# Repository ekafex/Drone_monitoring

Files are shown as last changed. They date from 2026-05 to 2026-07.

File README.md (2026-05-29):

# Drone Atmospheric Monitoring Project 

This is an **R&D project funded by a AADF/READ grant** to build a **mobile atmospheric monitoring system** using a drone platform. The system architecture consists of **three measurement nodes**:

* **1 drone-mounted monitoring station**
* **1 fixed ground reference station**
* **1 mobile ground monitoring station** 

The drone platform is a **DJI Matrice 350 RTK**.

## Project Goal

Develop a **low-cost environmental monitoring system** capable of:

* mapping **air-pollution hotspots**
* performing **vertical atmospheric profiles**
* comparing drone measurements with **ground reference stations**

The system focuses on **relative air-quality indices rather than regulatory-grade concentrations**, to reduce integration complexity and cost.

## Sensor Strategy

Instead of multiple individual sensors (PM + gas + environmental), the system uses a **single integrated environmental node**:

**Primary sensor**

* **Sensirion SEN55**

    * PM1 / PM2.5 / PM4 / PM10
    * Temperature
    * Humidity
    * VOC index
    * NOx index
    * I²C interface

Advantages:

* factory calibrated
* digital output
* minimal analog electronics
* easier integration and maintenance

Optional upgrades discussed:

* **SCD4x CO₂ sensor**
* **SPS30 PM sensor for cross-validation**

## Electronics Architecture

Each station uses the same electronics design.

Core components:

**Microcontroller**

* ESP32-S3-DevKitC-1U development board

**Positioning**

* u-blox NEO-M9N GNSS module

**Communication**

* LoRa (868 MHz) telemetry

**Data storage**

* microSD logging

**Power**

* LiPo battery (drone/mobile)
* DC-DC regulators

## Communication Architecture

Telemetry uses **point-to-point LoRa (868 MHz)**.

Structure:

Drone node
→ LoRa
→ Ground station receiver

A LoRaWAN gateway is optional for later expansion.

## Airflow and Sensor Placement

Drone airflow strongly affects measurements.

Recommended design:

* **Side boom mounting**
* sensor inlet placed **~0.7–1.0 m from drone center**
* **aspirated sampling inlet** using a small fan
* **short inlet tubing**

This minimizes rotor downwash interference.

## Calibration Strategy

Because the system uses **relative air-quality indices**, calibration relies on **co-location** instead of expensive gas calibrators.

Procedure:

1. Run all stations **side-by-side for 1–2 weeks**
2. Compare sensor outputs
3. derive correction factors
4. validate against any available **reference station**

Industrial calibration devices exist but are **too expensive** for this project.

## Flight Sampling Protocol

Recommended drone measurement strategy:

1. Fly to location
2. **hover sampling segments (10–30 s)**
3. move to next point
4. repeat

Avoid measuring during rapid motion.

Use:

* vertical profiles
* grid sampling
* repeated transects

## System Deployment

Final system will include:

**Drone station**

* SEN55
* ESP32
* GNSS
* LoRa
* microSD
* aspirated inlet

**Fixed ground station**

* same sensors
* weatherproof enclosure
* continuous operation

**Mobile ground station**

* same hardware
* portable enclosure

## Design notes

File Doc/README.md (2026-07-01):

# PCB wiring



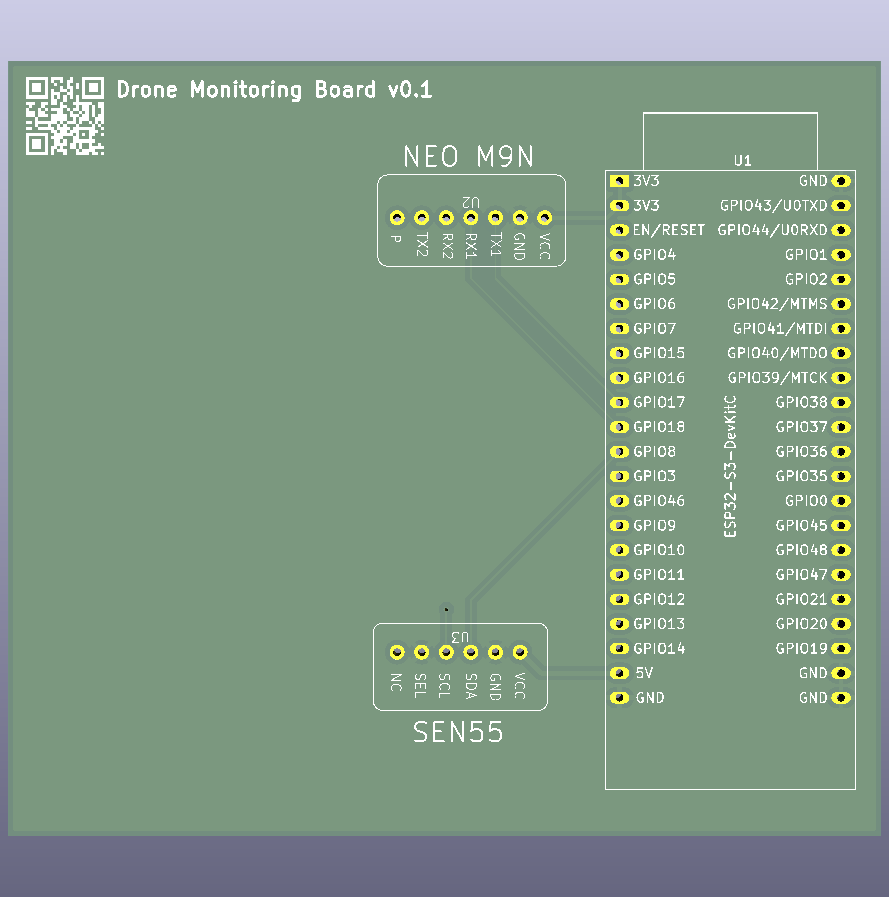
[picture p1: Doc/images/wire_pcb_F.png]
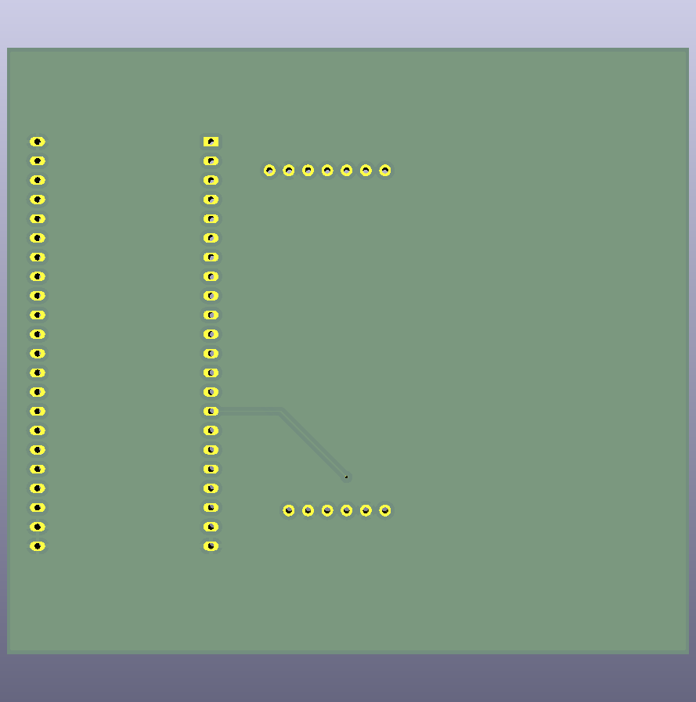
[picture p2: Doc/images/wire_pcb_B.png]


## ESP32-S3-DevKitC-1u

User guide for [ESP32-S3-DevKitC-1](https://docs.espressif.com/projects/esp-dev-kits/en/latest/esp32s3/esp32-s3-devkitc-1/user_guide_v1.1.html)

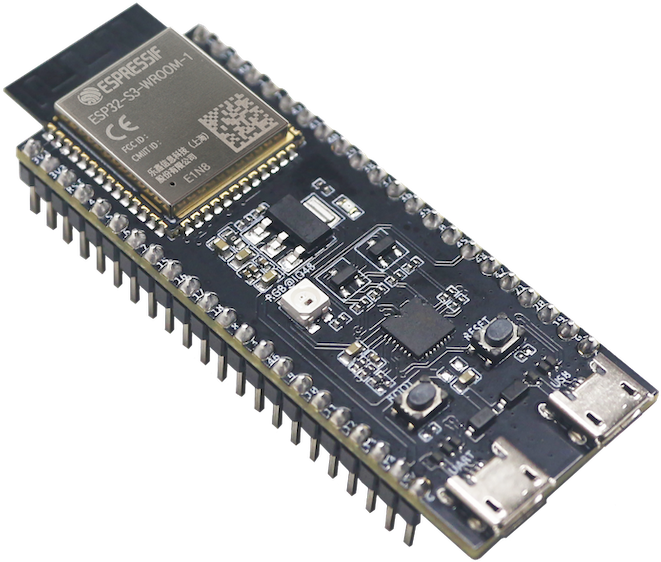
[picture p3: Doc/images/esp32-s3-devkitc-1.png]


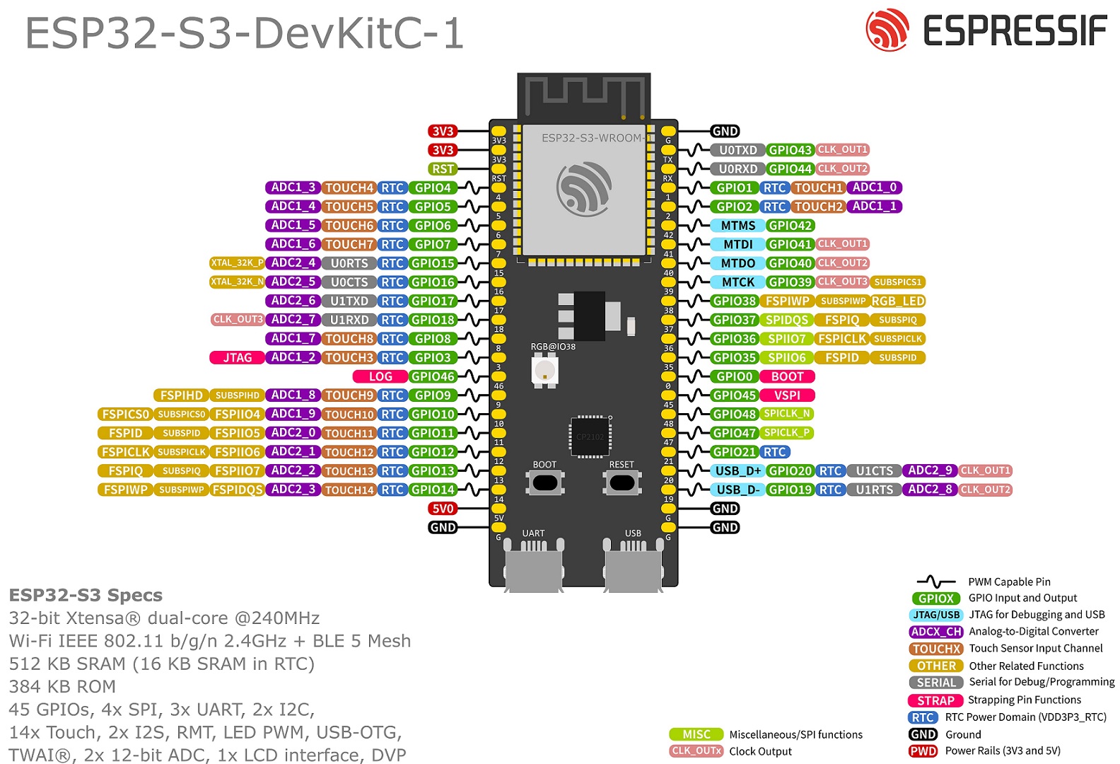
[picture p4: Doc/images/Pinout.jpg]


## Sensirion SEN55

[SEN55 Datasheet](https://sensirion.com/products/catalog/SEN55)

This is the Sensirion SEN5X library for Arduino using the
modules I2C interface.

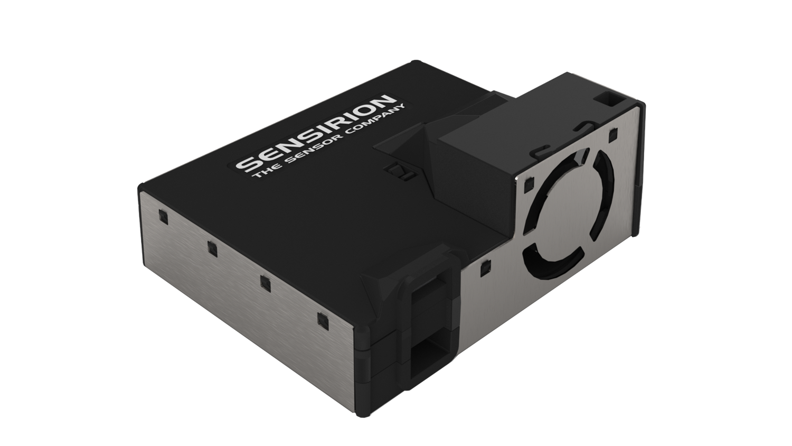
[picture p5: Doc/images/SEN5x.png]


| *SEN5X* |  *Arduino*  | *Jumper Wire* | ESP32 pin |
| :-----: | :---: | :---: | :---: |
| VCC | 5V | Red | 5V |
| GND | GND | Black | GND |
| SDA | SDA | Green | GPIO8 |
| SCL | SCL | Yellow | GPIO9 |
| SEL | GND for I2C | Blue | GND |

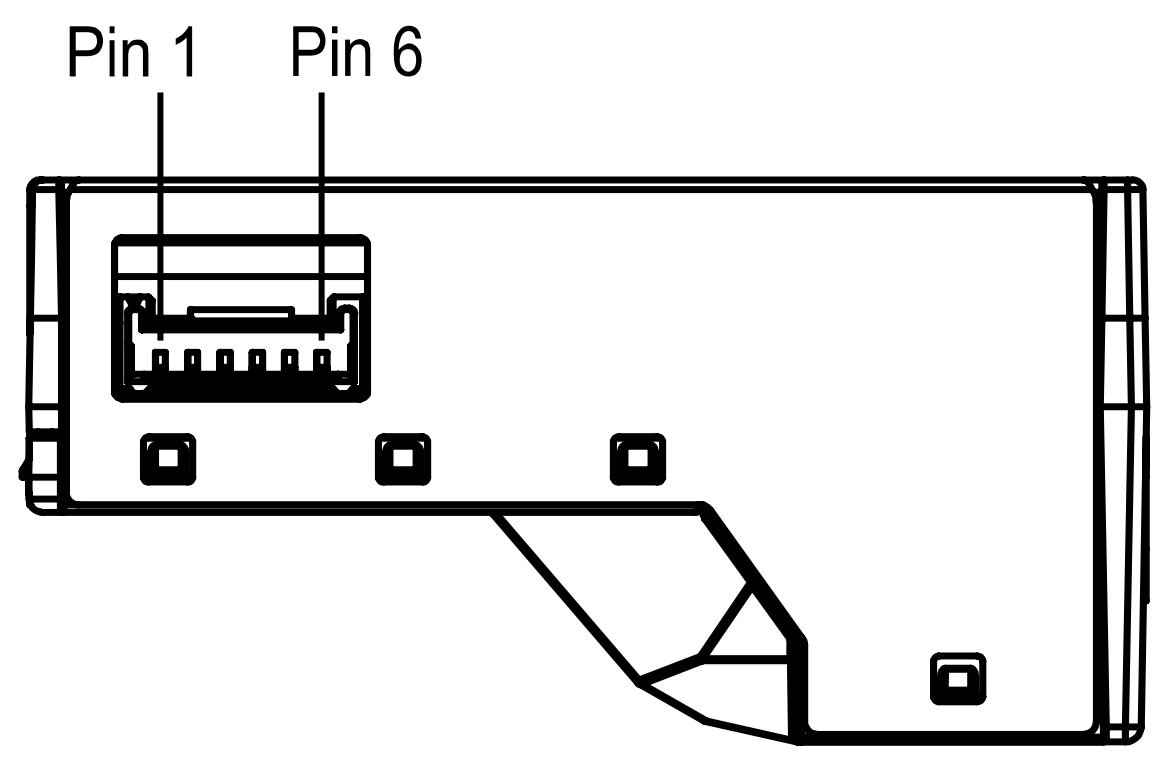
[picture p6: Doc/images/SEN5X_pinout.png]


| *Pin* | *Name* | *Description* | *Comments* |
| ----- | --- | --- | --- |
| 1 | VCC | Supply Voltage | 5V ±10% |
| 2 | GND | Ground |
| 3 | SDA | I2C: Serial data input / output | TTL 5V and LVTTL 3.3V compatible |
| 4 | SCL | I2C: Serial clock input | TTL 5V and LVTTL 3.3V compatible |
| 5 | SEL | Interface select | Pull to GND to select I2C |
| 6 | NC | Do not connect |

## UBLOX NEO M9N-00B

[Ublox NEO M9N-00B](https://www.u-blox.com/en/product/neo-m9n-module?legacy=Current#Documentation-&-resources)

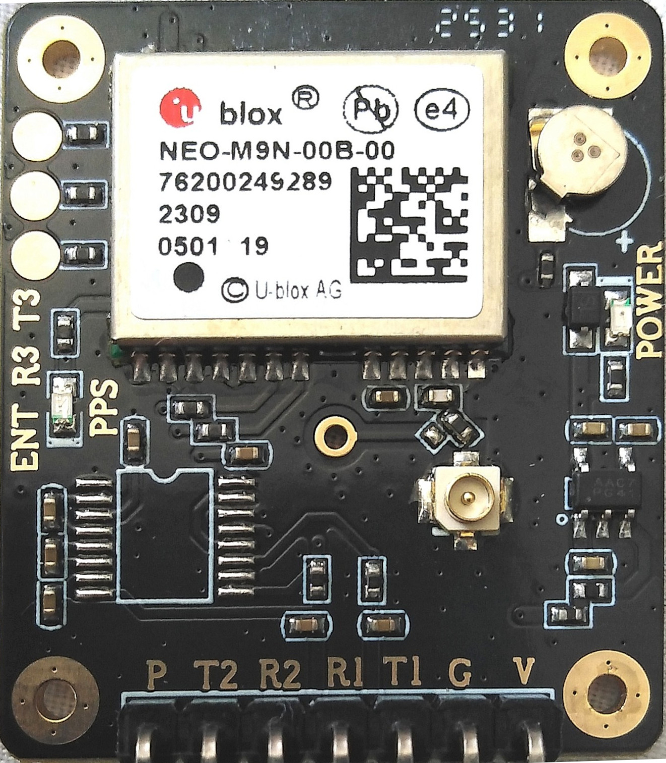
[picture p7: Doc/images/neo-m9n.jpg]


## LoRa LAMBDA62-8S (868MHz)

[LAMBDA62 Datasheet](https://www.rfsolutions.co.uk/radio-modules/lambda-62-lora-transceiver-module-20km-featuring-semtech-sx1262/)

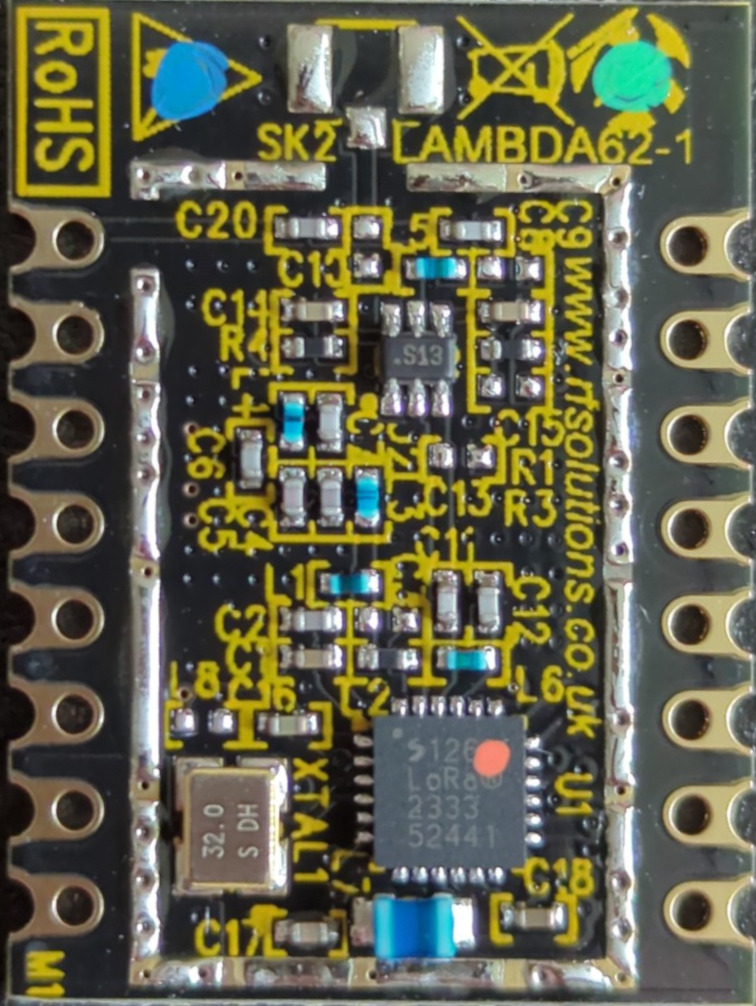
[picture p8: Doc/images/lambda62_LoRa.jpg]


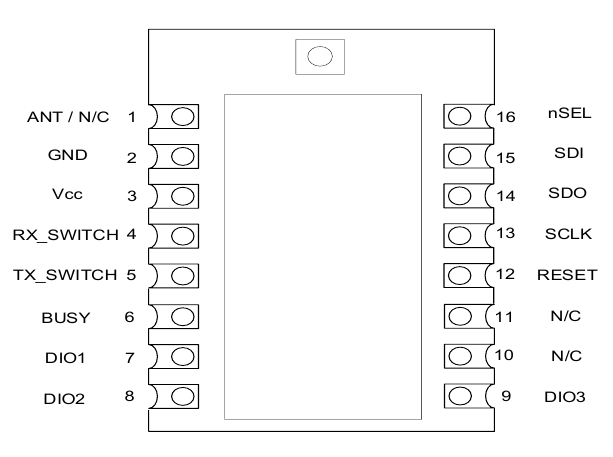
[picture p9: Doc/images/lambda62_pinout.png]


## Adafruit MicroSD BFF

[Reference](https://www.adafruit.com/product/5683)

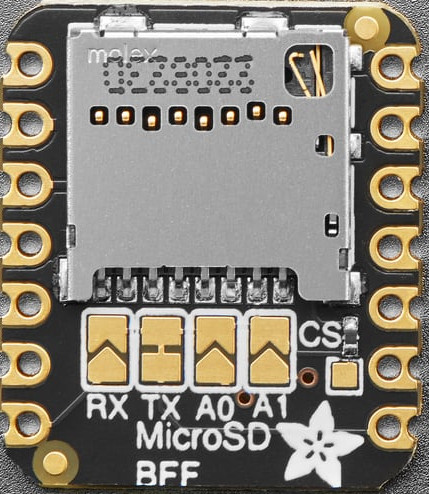
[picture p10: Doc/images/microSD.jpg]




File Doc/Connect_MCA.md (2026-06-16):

## RTEC digiBASE-RH Python acquisition setup

### 1. Linux / Debian / Raspberry Pi OS

Install system USB support and Python tools:

```bash
sudo apt update
sudo apt install python3 python3-venv python3-pip libusb-1.0-0
```

Create an environment:

```bash
python3 -m venv ~/venvs/digibase
source ~/venvs/digibase/bin/activate
pip install --upgrade pip
pip install digibase numpy matplotlib pyusb
```

Create the firmware directory:

```bash
mkdir -p ~/.digiBase
```

Copy ORTEC firmware files there:

```bash
cp digiBase.rbf ~/.digiBase/
cp digiBaseRH.rbf ~/.digiBase/
```

Set USB permissions:

```bash
sudo nano /etc/udev/rules.d/99-ortec-digibase.rules
```

Add:

```text
SUBSYSTEM=="usb", ATTR{idVendor}=="0a2d", ATTR{idProduct}=="001f", MODE="0666", GROUP="plugdev"
```

Reload:

```bash
sudo udevadm control --reload-rules
sudo udevadm trigger
sudo usermod -aG plugdev $USER
```

Then unplug/replug the digiBASE and log out/in.

Check:

```bash
lsusb
```

Expected:

```text
0a2d:001f ORTEC digiBASE-RH
```

### 2. Windows

There are two routes.

For **official ORTEC software**, install ORTEC CONNECTIONS/MAESTRO and use the vendor driver. The digiBASE manual describes installation through CONNECTIONS Driver Update Kit, MAESTRO, and MCB Configuration. ([ManualsLib](https://www.manualslib.com/manual/1990334/Ametek-Ortec-Digibase.html?utm_source=chatgpt.com))

For **Python/libusb access**, install:

```powershell
python -m pip install digibase numpy matplotlib pyusb
```

Then copy:

```text
digiBase.rbf
digiBaseRH.rbf
```

to a convenient folder, for example:

```text
C:\Users\<your-user>\.digiBase\
```

If Python cannot open the USB device, Windows likely needs a generic USB driver such as **WinUSB** or **libusbK** installed for the digiBASE interface. Zadig is commonly used for this purpose; it installs generic USB drivers such as WinUSB/libusbK for libusb-based applications. ([AlternativeTo](https://alternativeto.net/software/zadig/about/?utm_source=chatgpt.com))

Important: replacing the ORTEC driver with WinUSB/libusbK may stop MAESTRO from seeing the device until you revert the driver.

## Minimal spectrum acquisition script

Save as `digibase_take_spectrum.py`:

```python
#!/usr/bin/env python3

import argparse
import time
from pathlib import Path

import numpy as np
import matplotlib.pyplot as plt

from digibase import digiBase

def main():
    parser = argparse.ArgumentParser(
        description="Acquire one PHA spectrum from an ORTEC digiBASE/digiBASE-RH."
    )

    parser.add_argument("--hv", type=float, default=600.0,
                        help="PMT high voltage in volts. Start conservatively.")
    parser.add_argument("--time", type=float, default=10.0,
                        help="Acquisition time in seconds.")
    parser.add_argument("--fine-gain", type=float, default=1.0,
                        help="ADC fine gain.")
    parser.add_argument("--lld", type=int, default=24,
                        help="Lower-level discriminator in ADC channels.")
    parser.add_argument("--out", type=str, default="spectrum",
                        help="Output basename without extension.")

    args = parser.parse_args()

    outbase = Path(args.out)

    print("Connecting to digiBASE...")
    base = digiBase()

    print(f"Serial number: {base.serial}")

    print(f"Setting HV = {args.hv} V")
    base.hv = args.hv
    base.hv_enabled = True

    print(f"Setting fine gain = {args.fine_gain}")
    base.fine_gain = args.fine_gain

    print(f"Setting LLD = {args.lld}")
    base.lld = args.lld

    print("Setting PHA mode")
    base.set_acq_mode_pha()

    print("Clearing previous spectrum if supported...")
    try:
        base.clear()
    except Exception:
        pass

    print("Starting acquisition...")
    base.start()

    time.sleep(args.time)

    print("Stopping acquisition...")
    base.stop()

    spectrum = np.asarray(base.spectrum, dtype=np.int64)
    channels = np.arange(len(spectrum))

    txt_file = outbase.with_suffix(".txt")
    csv_file = outbase.with_suffix(".csv")
    png_file = outbase.with_suffix(".png")

    np.savetxt(txt_file, spectrum, fmt="%d")

    data = np.column_stack([channels, spectrum])
    np.savetxt(
        csv_file,
        data,
        delimiter=",",
        header="channel,counts",
        comments="",
        fmt=["%d", "%d"],
    )

    plt.figure()
    plt.plot(channels, spectrum)
    plt.xlabel("Channel")
    plt.ylabel("Counts")
    plt.title(f"digiBASE spectrum, {args.time:g} s, HV={args.hv:g} V")
    plt.grid(True)
    plt.tight_layout()
    plt.savefig(png_file, dpi=150)
    plt.show()

    print()
    print("Acquisition complete.")
    print(f"Channels:     {len(spectrum)}")
    print(f"Total counts: {spectrum.sum()}")
    print(f"Peak channel: {spectrum.argmax()}")
    print(f"Saved:        {txt_file}")
    print(f"Saved:        {csv_file}")
    print(f"Saved:        {png_file}")

if __name__ == "__main__":
    main()
```

Run:

```bash
python digibase_take_spectrum.py --hv 600 --time 30 --fine-gain 1.0 --lld 24 --out test_30s
```

This produces:

```text
test_30s.txt
test_30s.csv
test_30s.png
```

Start with a safe low HV, then increase only according to your PMT/scintillator specifications.

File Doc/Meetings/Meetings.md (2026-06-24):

# Group Meetings Detyrat

| Data Mbledhjes | Data Raportimit | Silvana | Gerti | Klaudio | Ervini |
| :---: | :---: | :--- | :--- | :--- | :--- |
| 16.06.2026 | **23.06.2026**  | Raport mbi instalimin dhe perdorimin e software-it te Evaluation Kit SEK-SEN55 | Raport mbi instalimin dhe data acquisition ne kompjuter nga gamma detector. Funksioni i librarise digibase ne python | Validimi i funksionit te te gjitha pajisjeve te blera per "Laboratorin e Aerodinamikes" | Raport mbi ecurine a firmware dhe lidhjes se te gjitha komponenteve baze te paketes se dronit (SEN55, GNSS, SD card & LoRa) |
| 23.06.2026 | **03.07.2026**  | Blerje online. Ri-evaluimi i buxhetit qe mund te alokohet per blerjet e reja. Raportim e ecurise | Venia ne pune e pajisjeve laboraorike. Raportim i ecurise | Investigimi i zhurmes e kanaleve te MCA te uleta. Rregullimi i delay ne matjet, dhe te kuptuarit e "list-mode". Raportim i ecurise. | Ndertimi i PCB per nensitemin e dronit me KiCAD. Raportimi i ecurise |
| | | | | | |

---

## Group Meeting Raportimet

| Data | Silvana | Gerti | Klaudio | Ervini |
| :---: | :--- | :--- | :--- | :--- |
| **23.06.2026** | 1. Software Sensiron u instalua por nuk punon pa u lidhur me sensorin (**status: pending**). 2. Nevoja per evaluation kit bridge per te lidhur sensorin me kompjuterin. | 1. Libraria funksionon, mund te lidhet ne menyre te sukseshme dhe te marri te dhena nga detektori gamma (**status: functional**). 2. Zhurme e pa identifikuar ne kanalet e uleta te MCA (**status: in progress**). 3. Perpjekje to mitigate duke bere nje delay midis powering dhe fillimit te matjeve (**status: in progress**). | 1. Te gjitha pajisjet e blera per laboratorin e aerodinamikes funksionojne. 2. Gypi pitot ka nevoje per nje mikrokontrollor per te lidhur me kompjuterin (Arduino nga lab i elektronikes). | 1. Shkrimi i draftit te pare te Firmware per paketen e dronit (**status: functional**). 2. Ndertimi i versionit v.0.1 e PCB manualisht (**status: functional**). 3. Ndertimi i wiring, BOM, dhe PCB profesionale ne KiCAD (**status: in progress**). |
| | | | | |

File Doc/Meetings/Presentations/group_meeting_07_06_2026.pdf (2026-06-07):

## Sistemi i Monitorimit Atmosferik me Dron

### Arkitektura e përditësuar, nënsistemet, varësitë dhe plani R&D

Draft për mbledhjen e grupit

Ervin K. – FSHN @ UT – Projekt R&D

June 7, 2026

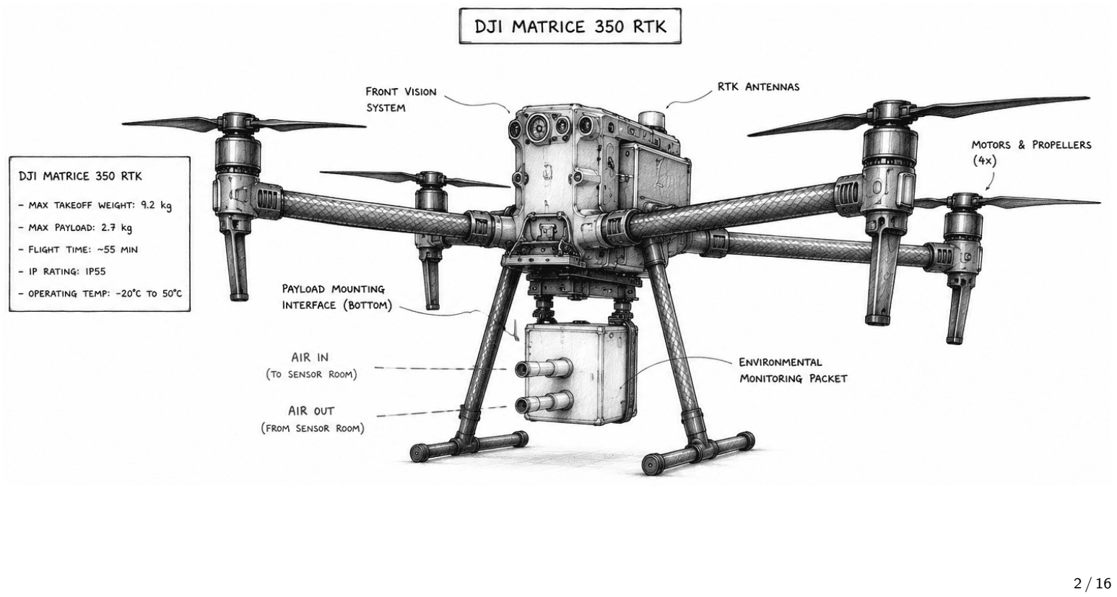
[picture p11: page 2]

### Qëllimi i kësaj mbledhjeje

Qëllimi kryesor
Të sinkronizojmë ekipin rreth arkitekturës aktuale të sistemit, përgjegjësive për nënsistemet, varësive dhe daljeve afatshkurtra.

### Duhet të qartësojmë - çfarë funksionon tashmë

### - çfarë mungon ende

### - çfarë e bllokon integrimin

### Dalja e mbledhjes - përgjegjësi të përditësuara për detyrat - afate realiste për nënsistemet

### - plan veprimi për 4–8 javët e ardhshme

### Arkitektura e përgjithshme e projektit

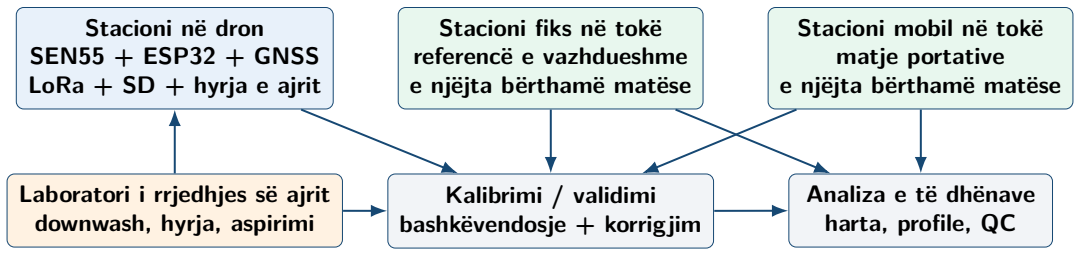
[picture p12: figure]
Stacioni në dron SEN55 + ESP32 + GNSS LoRa + SD + hyrja e ajrit; Stacioni fiks në tokë referencë e vazhdueshme e njëjta bërthamë matëse; Stacioni mobil në tokë matje portative e njëjta bërthamë matëse; Laboratori i rrjedhjes së ajrit downwash, hyrja, aspirimi; Kalibrimi / validimi bashkëvendosje + korrigjim; Analiza e të dhënave harta, profile, QC

### Afati i projektit: nga prototipi te matjet në terren

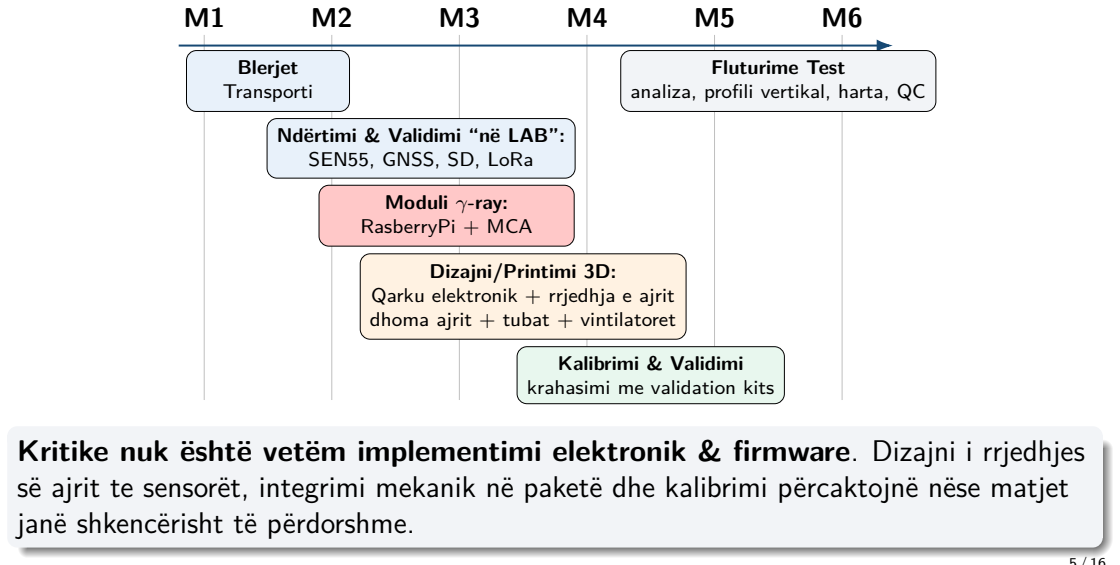
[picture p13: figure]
Blerjet Transporti; Ndërtimi & Validimi; “në LAB”:; SEN55, GNSS, SD, LoRa; Moduli γ-ray:; RasberryPi; + MCA; Dizajni/Printimi 3D: Qarku elektronik + rrjedhja e ajrit dhoma ajrit + tubat + vintilatoret; Kalibrimi & Validimi krahasimi me validation kits; Fluturime Test analiza, profili vertikal, harta, QC; janë shkencërisht të përdorshme.

Kritike nuk është vetëm implementimi elektronik & firmware. Dizajni i rrjedhjes së ajrit te sensorët, integrimi mekanik në paketë dhe kalibrimi përcaktojnë nëse matjet

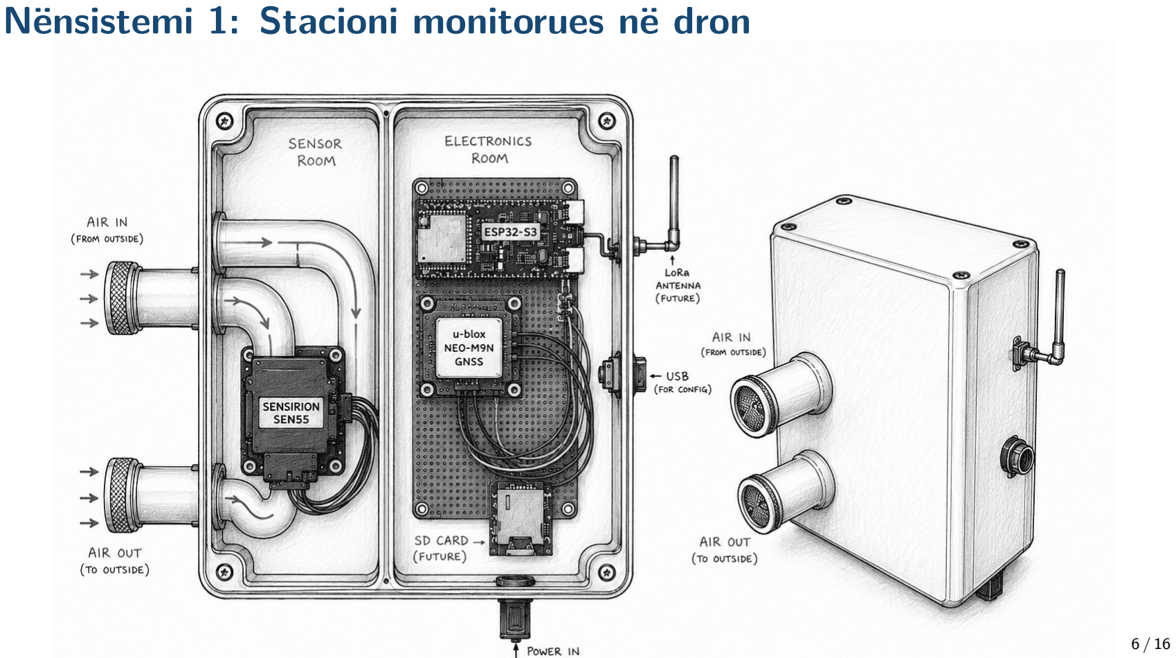
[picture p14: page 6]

### Nënsistemi 1: Stacioni monitorues në dron

### Nënsistemi 1: Stacioni monitorues në dron

Qëllimi
Të masë indikatorët atmosferikë përgjithësisht në profilin vertikal.
- Statusi: Vënia në punë e SEN55 dhe
GNSS ka filluar / është validuar
pjesërisht.
- Përgjegjësit: Ervini & Silvana
- Objektivi: Prototip në tavolinë & prototip i sigurt për dronin.
- Input: firmware, kapsula, krahët anësor (tubat), hyrje ajri, powerbank.
- Output: Një nyje në dron që prodhon te dnenat: data, ora, lat, long, alt, PM-t, VOC, NOx, Temp., RH
- Përdoret nga: kalibrimi, protokolli i fluturimit, analiza e të dhënave.
- Rreziqe/çështje të hapura: bias nga rrjedhja ajrit (droni/paketa), vibrimet, zhurmat, siguria në dron.

### Nënsistemi 2: Stacioni fiks në tokë

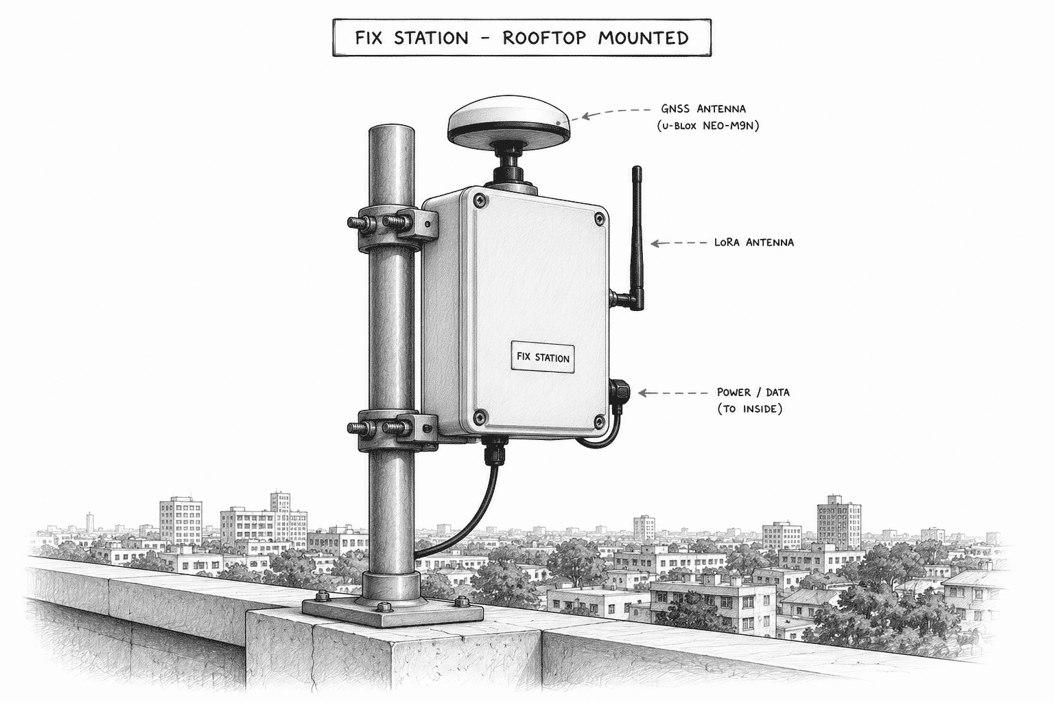
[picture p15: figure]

### Nënsistemi 2: Stacioni fiks në tokë

Qëllimi
Të ofrojë të dhëna lokale të vazhdueshme për krahasim, ndjekje të driftit dhe kalibrim me bashkëvendosje.
- Statusi: Arkitektura hardware është
përcaktuar; kapsulimi dhe rrjedhja e ajrit duhen ende validuar.
- Përgjegjësit: Silvana & Ervini
- Objektivi: Prototip për funksionim të vazhdueshëm jashtë.
- Input: SEN55, ESP32, GNSS/koha, ⃗v erës, SD, ventilator, kasë, energji.
- Output: Seri kohore stabël: data, ora, lat, long, alt, PM-t, VOC, NOx, Temp., RH, ⃗v e erës
- Përdoret nga: kalibrimi, validimi, matjet bazë.
- Rreziqe/çështje të hapura: mbrojtja nga moti, dizajni i hyrjes së ajrit, energjia afatgjatë, bias termik.

### Nënsistemi 3: Stacioni mobil në tokë

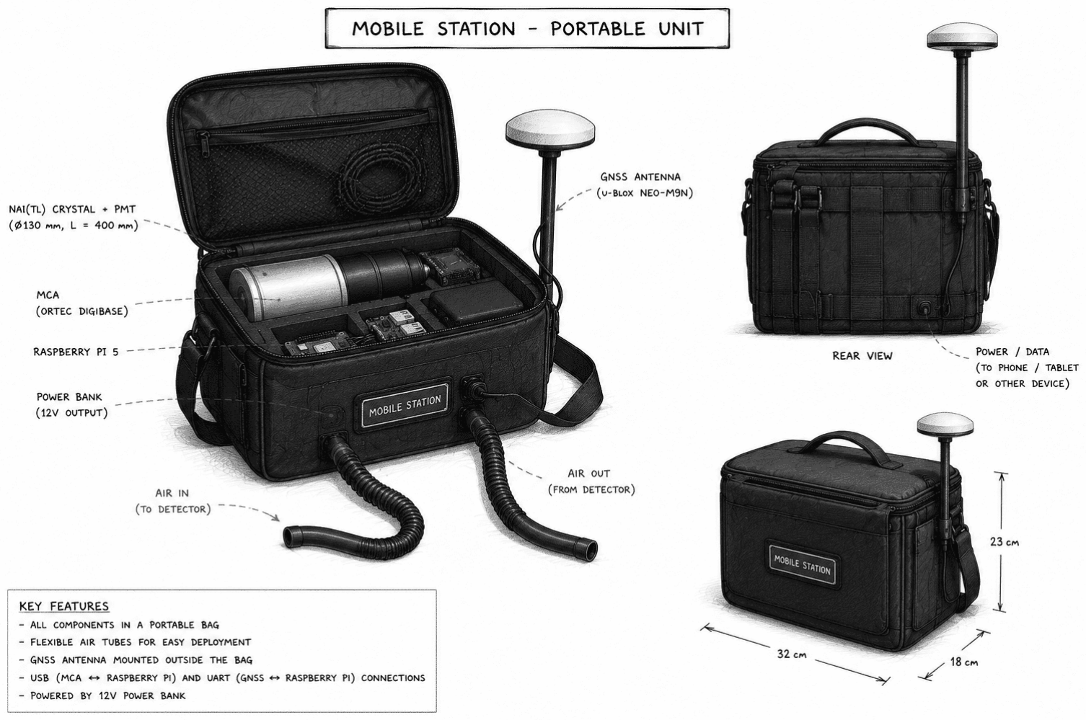
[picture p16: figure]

### Nënsistemi 3: Stacioni mobil në tokë

Qëllimi
Të mbështesë matje portative në tokë dhe të japë të dhëna krahasuese pranë vendndodhjeve të matjeve me dron.
- Statusi: E njëjta bërthamë elektronike
si stacioni fiks; kasa portative është në pritje.
- Përgjegjësit: Klaudio & Gerti
- Objektivi: Nyjë portative me bateri.
- Output: Matje të gjeolokalizuara në ecje / të mbajtura / mobile.
- Input: firmuer i përbashkët, bateri, kasë, dorezë/montim, SD.
- Përdoret nga: matje të hotspoteve, krahasim dron-tokë, validim hartash.
- Rreziqe/çështje të hapura: artefakte nga lëvizja, ekspozim ndaj temperaturës, lartësi jo e njëtrajtshme e mostrimit.

### Nënsistemi 4: Stacioni γ-ray

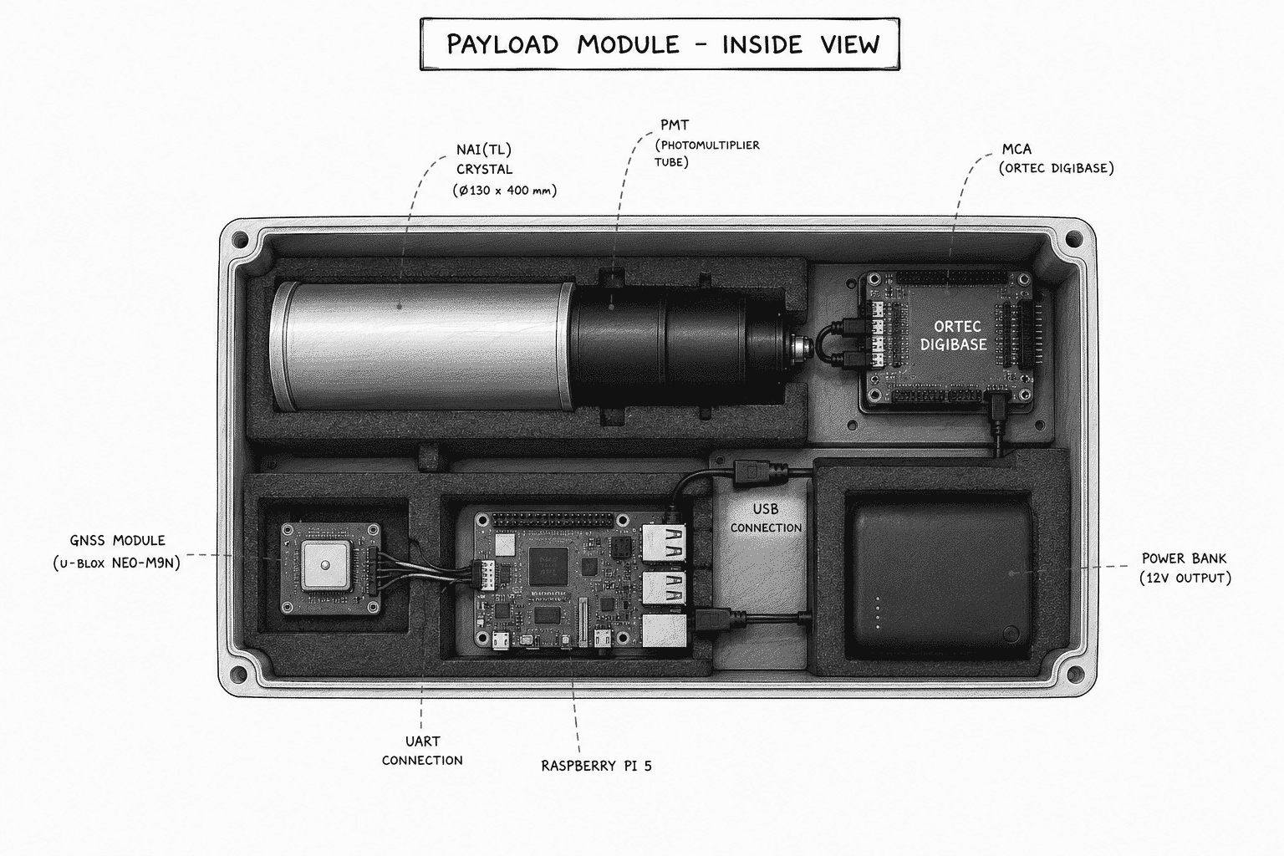
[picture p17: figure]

### Nënsistemi 4: Stacioni γ-ray

Qëllimi
Te ndërtojë harta të hotspoteve radioaktive me dron.
- Statusi: Detectori NaI + PMT + MCA
& Rasberry Pi + GNSS + LoRa + SD.
- Përgjegjësit: Gerti & Ervini
- Objektivi: Nyjë portative me bateri (powerbank).
- Input: Simulimet Geant4, firmware, bateri, kasë montim dron.
- Output: Heatmap: channel counts vs. time.
- Përdoret nga: hotspot maps, validim hartash radioaktiviteti.
- Rreziqe/çështje të hapura: Pesha detektorit, koha e ekspozimit/koha baterise se dronit.

### Nënsistemi 5: Laboratori i rrjedhjes së ajrit

Qëllimi
Të studiojmë nivelin e turbullimit të ajrit nga helikat e dronit, optimizimin e rrjedhjes së ajrit në dhomën e sensorëve dhe optimizimin e aerodinamikës së paketave në dron.
- Statusi: Kanë ardhur pajisjet ???
- Përgjegjësit: Klaudio & Gerti
- Objektivi: Të ngrihet lab për të studiuar turbullirat e dronit.
- Input: Simulimet aerodinamike.
- Output: Hartën 3D të shpejtësisë së ajrit rrotull dronit.
- Përdoret nga: Dizajni mekanik.
- Rreziqe/çështje të hapura: Mungesa e gjithë pajisjeve laboratorike për të bërë matjet. Mungesë eksperience në simulimet aerodinamike

### Grupet që duhen ngritur

Grupet
- Shkrim Firmware
- Dizajn Qarku/PCB
- Telemetria LoRa
- Dizajni CAD dhe Printimi 3D i pjesëve mekanike
- Kalibrimi dhe Validimi përdorimi i “Validation Kits”
- Pipeline & Databaza
- Sofware: Analizë & Vizualizimin e të dhënave

Vendime për t’u marrë sot:
1. Përgjegjësat për secilin nënsistem?
2. Funksionaliteti minmal i pajisjes për të filluar testet e para me dron?
3. Strategjia për dizajnin e kasave të stacionit fiks dhe atij mobil?
4. Cilat teste të rrjedhjes së ajrit janë të detyrueshme para montimit në dron?
5. Cili format log-u duhet bërë standard i projektit?
6. Cila është data e matjeve te para?

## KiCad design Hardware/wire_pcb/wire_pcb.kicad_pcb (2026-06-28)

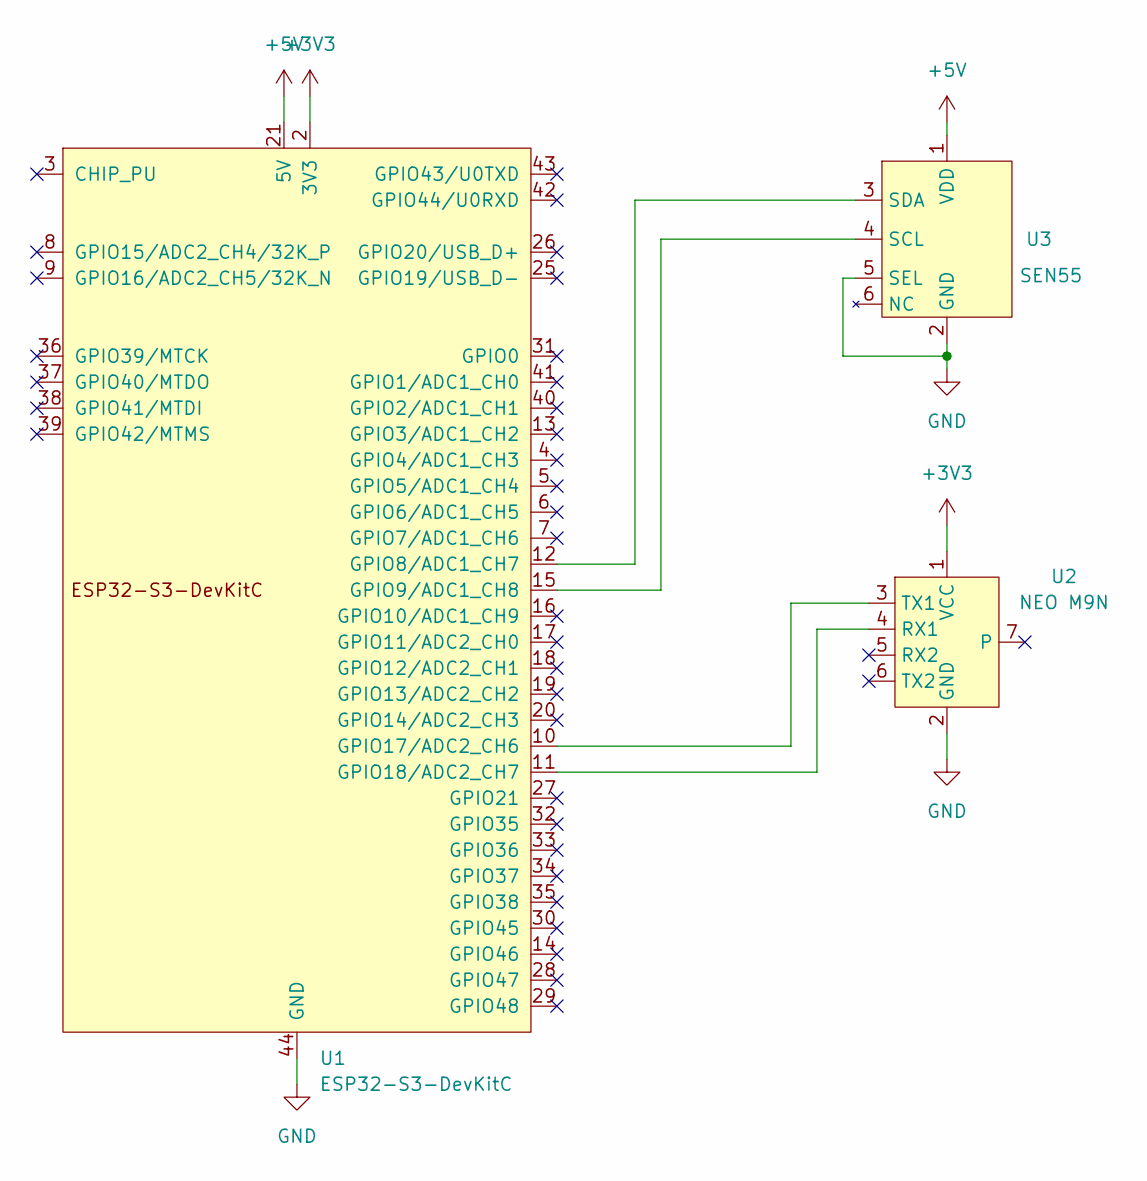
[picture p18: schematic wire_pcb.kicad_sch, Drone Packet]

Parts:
U1: ESP32-S3-DevKitC
U2: NEO M9N
U3: SEN55

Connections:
+3V3: U1.1 (3V3), U1.2 (3V3), U2.1 (VCC)
+5V: U1.21 (5V), U3.1 (VDD)
GND: U1.22 (GND), U1.23 (GND), U1.24 (GND), U1.44 (GND), U2.2 (GND), U3.2 (GND), U3.5 (SEL)
unnamed: U1.12 (GPIO8/ADC1_CH7), U3.3 (SDA)
unnamed: U1.15 (GPIO9/ADC1_CH8), U3.4 (SCL)
unnamed: U1.10 (GPIO17/ADC2_CH6), U2.3 (TX1)
unnamed: U1.11 (GPIO18/ADC2_CH7), U2.4 (RX1)

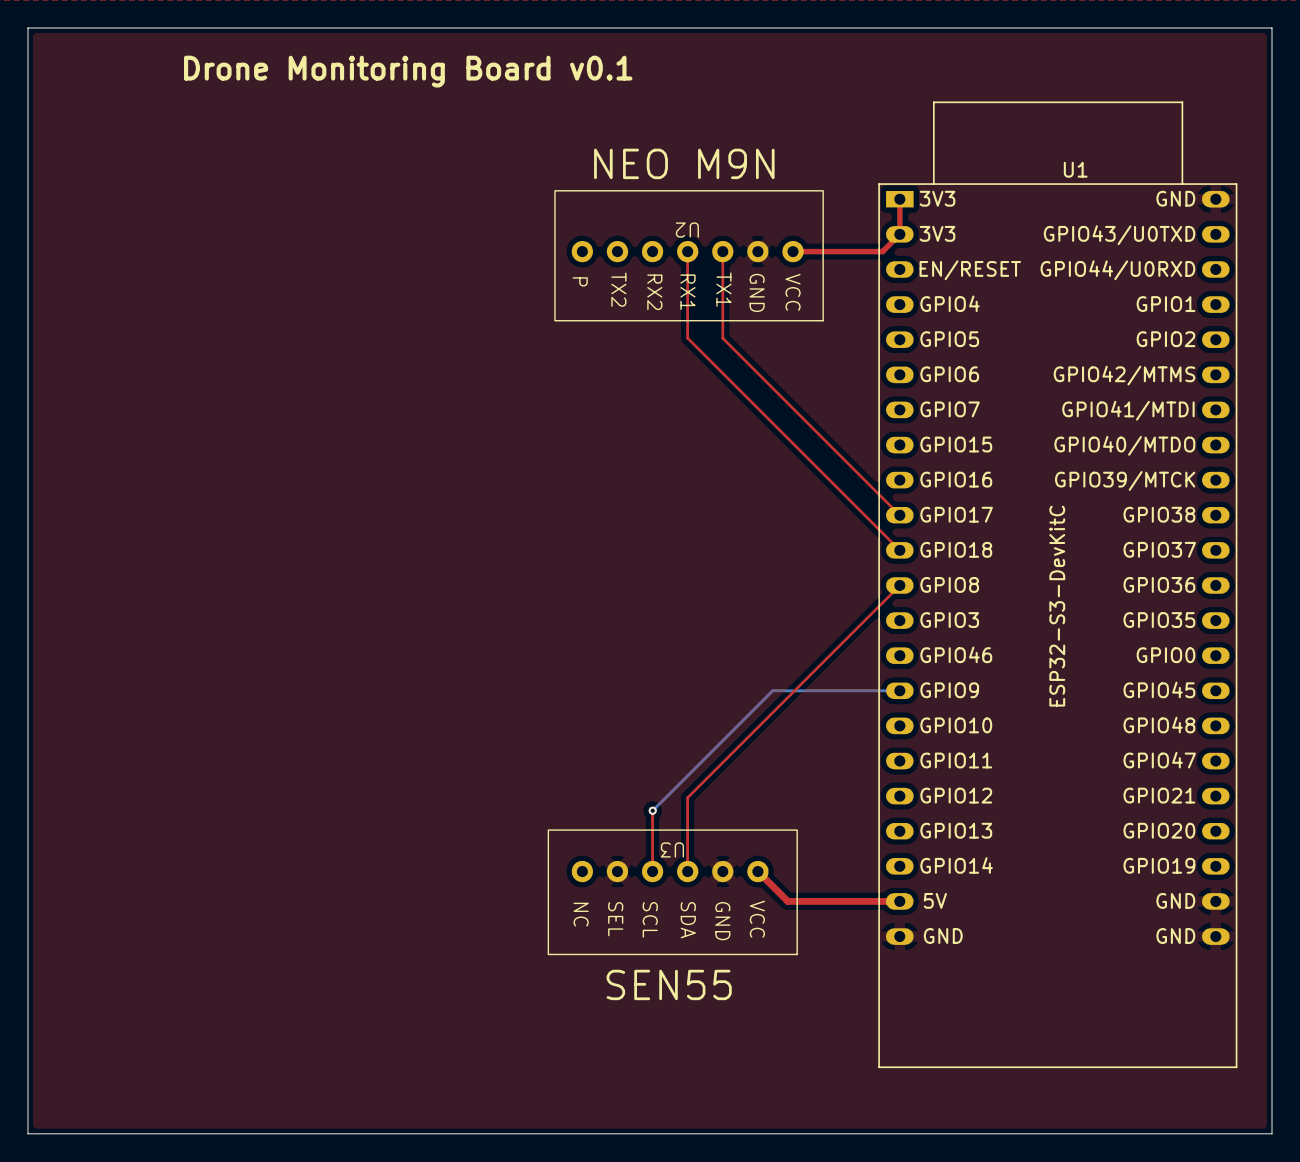
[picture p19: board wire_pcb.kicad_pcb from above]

Board: 2 copper layers, 90.0 x 80.0 mm, 3 parts (0 on the bottom side), 7 nets.

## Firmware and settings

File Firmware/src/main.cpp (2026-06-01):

#include <Arduino.h>
#include <Wire.h>
#include <math.h>

#include <SensirionI2CSen5x.h>
#include <SparkFun_u-blox_GNSS_v3.h>

// -----------------------------------------------------------------------------
// Pin configuration
// -----------------------------------------------------------------------------

constexpr uint8_t I2C_SDA_PIN = 8;
constexpr uint8_t I2C_SCL_PIN = 9;

constexpr uint8_t GNSS_RX_PIN = 18;  // ESP32 RX  <- GNSS T1 / TX
constexpr uint8_t GNSS_TX_PIN = 17;  // ESP32 TX  -> GNSS R1 / RX

constexpr uint32_t SERIAL_BAUD = 115200;
constexpr uint32_t GNSS_BAUD_PRIMARY = 38400;
constexpr uint32_t GNSS_BAUD_FALLBACK = 9600;

// SEN55 should normally be read at ~1 Hz.
constexpr uint32_t SEN55_READ_PERIOD_MS = 1000;

// GNSS PVT can be polled faster; it will only update when new data are ready.
constexpr uint32_t GNSS_POLL_PERIOD_MS = 200;

// For now this is the period of the combined printed/logged record.
// Later this can become the SD-card / LoRa publication period.
constexpr uint32_t RECORD_PERIOD_MS = 1000;

// -----------------------------------------------------------------------------
// Global driver objects
// -----------------------------------------------------------------------------

SensirionI2CSen5x sen5x;
HardwareSerial GNSSSerial(1);
SFE_UBLOX_GNSS_SERIAL gnss;

// -----------------------------------------------------------------------------
// Data structures
// -----------------------------------------------------------------------------

struct Sen55Sample {
    bool valid = false;
    uint32_t timestamp_ms = 0;

    float pm1p0 = NAN;
    float pm2p5 = NAN;
    float pm4p0 = NAN;
    float pm10p0 = NAN;

    float humidity = NAN;
    float temperature = NAN;
    float vocIndex = NAN;
    float noxIndex = NAN;
};

struct GnssSample {
    bool valid = false;
    uint32_t timestamp_ms = 0;

    double latitude_deg = NAN;
    double longitude_deg = NAN;
    double altitude_msl_m = NAN;

    uint8_t satellites = 0;
    uint8_t fixType = 0;

    uint16_t year = 0;
    uint8_t month = 0;
    uint8_t day = 0;
    uint8_t hour = 0;
    uint8_t minute = 0;
    uint8_t second = 0;
};

struct MeasurementRecord {
    uint32_t timestamp_ms = 0;
    Sen55Sample sen55;
    GnssSample gnss;
};

Sen55Sample latestSen55;
GnssSample latestGnss;

// -----------------------------------------------------------------------------
// Small utility functions
// -----------------------------------------------------------------------------

void printSensirionError(const char* operation, uint16_t error)
{
    char errorMessage[256];
    errorToString(error, errorMessage, sizeof(errorMessage));

    Serial.print("[SEN55] ");
    Serial.print(operation);
    Serial.print(" failed: ");
    Serial.println(errorMessage);
}

void printFloatOrNA(float value, uint8_t digits)
{
    if (isnan(value)) {
        Serial.print("n/a");
    } else {
        Serial.print(value, digits);
    }
}

void printDoubleOrNA(double value, uint8_t digits)
{
    if (isnan(value)) {
        Serial.print("n/a");
    } else {
        Serial.print(value, digits);
    }
}

// -----------------------------------------------------------------------------
// SEN55 subsystem
// -----------------------------------------------------------------------------

bool initSen55()
{
    Wire.begin(I2C_SDA_PIN, I2C_SCL_PIN);
    sen5x.begin(Wire);

    uint16_t error = sen5x.deviceReset();
    if (error) {
        printSensirionError("deviceReset", error);
        return false;
    }

    delay(100);

    const float tempOffset = 0.0f;
    error = sen5x.setTemperatureOffsetSimple(tempOffset);
    if (error) {
        printSensirionError("setTemperatureOffsetSimple", error);
        // Not fatal for basic operation.
    } else {
        Serial.print("[SEN55] Temperature offset set to ");
        Serial.print(tempOffset);
        Serial.println(" deg C");
    }

    error = sen5x.startMeasurement();
    if (error) {
        printSensirionError("startMeasurement", error);
        return false;
    }

    Serial.println("[SEN55] Measurement started");
    return true;
}

bool readSen55(Sen55Sample& sample)
{
    sample.timestamp_ms = millis();

    uint16_t error = sen5x.readMeasuredValues(
        sample.pm1p0,
        sample.pm2p5,
        sample.pm4p0,
        sample.pm10p0,
        sample.humidity,
        sample.temperature,
        sample.vocIndex,
        sample.noxIndex
    );

    if (error) {
        sample.valid = false;
        printSensirionError("readMeasuredValues", error);
        return false;
    }

    sample.valid = true;
    return true;
}

// -----------------------------------------------------------------------------
// GNSS subsystem
// -----------------------------------------------------------------------------

bool tryBeginGnssAtBaud(uint32_t baud)
{
    GNSSSerial.end();
    delay(50);

    GNSSSerial.begin(baud, SERIAL_8N1, GNSS_RX_PIN, GNSS_TX_PIN);
    delay(200);

    Serial.print("[GNSS] Trying UART baud ");
    Serial.println(baud);

    return gnss.begin(GNSSSerial);
}

bool initGnss()
{
    if (!tryBeginGnssAtBaud(GNSS_BAUD_PRIMARY)) {
        if (!tryBeginGnssAtBaud(GNSS_BAUD_FALLBACK)) {
            Serial.println("[GNSS] Not detected");
            return false;
        }
    }

    Serial.println("[GNSS] Detected");

    // Use UBX binary output on UART1. This reduces unnecessary NMEA traffic.
    // If this call fails, basic reading can still work.
    if (!gnss.setUART1Output(COM_TYPE_UBX)) {
        Serial.println("[GNSS] Warning: could not set UART1 output to UBX only");
    }

    return true;
}

bool readGnss(GnssSample& sample)
{
    // getPVT returns true when a fresh PVT solution is available.
    if (!gnss.getPVT()) {
        return false;
    }

    sample.timestamp_ms = millis();

    sample.latitude_deg = gnss.getLatitude() / 10000000.0;
    sample.longitude_deg = gnss.getLongitude() / 10000000.0;
    sample.altitude_msl_m = gnss.getAltitudeMSL() / 1000.0;

    sample.satellites = gnss.getSIV();
    sample.fixType = gnss.getFixType();

    sample.year = gnss.getYear();
    sample.month = gnss.getMonth();
    sample.day = gnss.getDay();
    sample.hour = gnss.getHour();
    sample.minute = gnss.getMinute();
    sample.second = gnss.getSecond();

    // fixType: 0 = no fix, 2 = 2D, 3 = 3D, etc.
    sample.valid = (sample.fixType >= 2);

    return true;
}

// -----------------------------------------------------------------------------
// Output / logging layer
// Later replace this with SD-card append + LoRa packet generation.
// -----------------------------------------------------------------------------

MeasurementRecord makeRecord()
{
    MeasurementRecord record;
    record.timestamp_ms = millis();
    record.sen55 = latestSen55;
    record.gnss = latestGnss;
    return record;
}

void printRecordHumanReadable(const MeasurementRecord& record)
{
    Serial.println();
    Serial.print("[RECORD] t_ms=");
    Serial.println(record.timestamp_ms);

    Serial.print("  SEN55 valid=");
    Serial.print(record.sen55.valid ? "yes" : "no");
    Serial.print(" PM1=");
    printFloatOrNA(record.sen55.pm1p0, 2);
    Serial.print(" PM2.5=");
    printFloatOrNA(record.sen55.pm2p5, 2);
    Serial.print(" PM4=");
    printFloatOrNA(record.sen55.pm4p0, 2);
    Serial.print(" PM10=");
    printFloatOrNA(record.sen55.pm10p0, 2);
    Serial.print(" H=");
    printFloatOrNA(record.sen55.humidity, 2);
    Serial.print(" T=");
    printFloatOrNA(record.sen55.temperature, 2);
    Serial.print(" VOC=");
    printFloatOrNA(record.sen55.vocIndex, 0);
    Serial.print(" NOx=");
    printFloatOrNA(record.sen55.noxIndex, 0);
    Serial.println();

    Serial.print("  GNSS valid=");
    Serial.print(record.gnss.valid ? "yes" : "no");
    Serial.print(" fixType=");
    Serial.print(record.gnss.fixType);
    Serial.print(" SIV=");
    Serial.print(record.gnss.satellites);
    Serial.print(" lat=");
    printDoubleOrNA(record.gnss.latitude_deg, 7);
    Serial.print(" lon=");
    printDoubleOrNA(record.gnss.longitude_deg, 7);
    Serial.print(" alt_m=");
    printDoubleOrNA(record.gnss.altitude_msl_m, 3);

    Serial.print(" UTC=");
    if (record.gnss.year > 0) {
        Serial.printf(
            "%04u-%02u-%02uT%02u:%02u:%02uZ",
            record.gnss.year,
            record.gnss.month,
            record.gnss.day,
            record.gnss.hour,
            record.gnss.minute,
            record.gnss.second
        );
    } else {
        Serial.print("n/a");
    }
    Serial.println();
}

// CSV is usually the most convenient first format for SD-card logging.
void printRecordCSVHeader()
{
    Serial.println(
        "t_ms,"
        "sen55_valid,pm1p0,pm2p5,pm4p0,pm10p0,humidity,temperature,voc_index,nox_index,"
        "gnss_valid,fix_type,siv,lat_deg,lon_deg,alt_msl_m,year,month,day,hour,minute,second"
    );
}

void printRecordCSV(const MeasurementRecord& r)
{
    Serial.print(r.timestamp_ms);
    Serial.print(',');

    Serial.print(r.sen55.valid ? 1 : 0);
    Serial.print(',');
    Serial.print(r.sen55.pm1p0, 2);
    Serial.print(',');
    Serial.print(r.sen55.pm2p5, 2);
    Serial.print(',');
    Serial.print(r.sen55.pm4p0, 2);
    Serial.print(',');
    Serial.print(r.sen55.pm10p0, 2);
    Serial.print(',');
    Serial.print(r.sen55.humidity, 2);
    Serial.print(',');
    Serial.print(r.sen55.temperature, 2);
    Serial.print(',');
    Serial.print(r.sen55.vocIndex, 0);
    Serial.print(',');
    Serial.print(r.sen55.noxIndex, 0);
    Serial.print(',');

    Serial.print(r.gnss.valid ? 1 : 0);
    Serial.print(',');
    Serial.print(r.gnss.fixType);
    Serial.print(',');
    Serial.print(r.gnss.satellites);
    Serial.print(',');
    Serial.print(r.gnss.latitude_deg, 7);
    Serial.print(',');
    Serial.print(r.gnss.longitude_deg, 7);
    Serial.print(',');
    Serial.print(r.gnss.altitude_msl_m, 3);
    Serial.print(',');
    Serial.print(r.gnss.year);
    Serial.print(',');
    Serial.print(r.gnss.month);
    Serial.print(',');
    Serial.print(r.gnss.day);
    Serial.print(',');
    Serial.print(r.gnss.hour);
    Serial.print(',');
    Serial.print(r.gnss.minute);
    Serial.print(',');
    Serial.println(r.gnss.second);
}

// -----------------------------------------------------------------------------
// Arduino entry points
// -----------------------------------------------------------------------------

void setup()
{
    Serial.begin(SERIAL_BAUD);
    delay(1000);

    Serial.println();
    Serial.println("Drone air-quality + GNSS prototype");
    Serial.println("-----------------------------------");

    const bool sen55OK = initSen55();
    const bool gnssOK = initGnss();

    if (!sen55OK) {
        Serial.println("[SYSTEM] SEN55 initialization failed");
    }

    if (!gnssOK) {
        Serial.println("[SYSTEM] GNSS initialization failed");
    }

    printRecordCSVHeader();
}

void loop()
{
    static uint32_t lastSen55ReadMs = 0;
    static uint32_t lastGnssPollMs = 0;
    static uint32_t lastRecordMs = 0;

    const uint32_t now = millis();

    if (now - lastSen55ReadMs >= SEN55_READ_PERIOD_MS) {
        lastSen55ReadMs = now;
        readSen55(latestSen55);
    }

    if (now - lastGnssPollMs >= GNSS_POLL_PERIOD_MS) {
        lastGnssPollMs = now;
        readGnss(latestGnss);
    }

    if (now - lastRecordMs >= RECORD_PERIOD_MS) {
        lastRecordMs = now;

        MeasurementRecord record = makeRecord();

        // For clean SD-card logging, keep CSV.
        printRecordCSV(record);

        // For debugging, temporarily use:
        // printRecordHumanReadable(record);
    }
}

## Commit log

2026-05-30 Added some sensor information + first firmware for reading data from SEN55 sensor
2026-06-02 Updated documentation
    [Adafruit microSD BFF.sch]
2026-06-28 Created Hardware folder and add first version of the wiring and PCB using KiCAD 10
    [wire_pcb.kicad_pcb, wire_pcb.kicad_sch]
2026-07-01 Updated PCB wiring schematics, Lora symbol wire in/out, and Doc/README.md.
